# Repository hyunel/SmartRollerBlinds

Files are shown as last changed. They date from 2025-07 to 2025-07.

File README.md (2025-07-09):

<p align="right">
English | <a href="./README.zh.md">中文</a>
</p>

# SmartRollerBlinds
> A low-cost, high-precision DIY smart roller blind motor solution based on ESP32-C3.

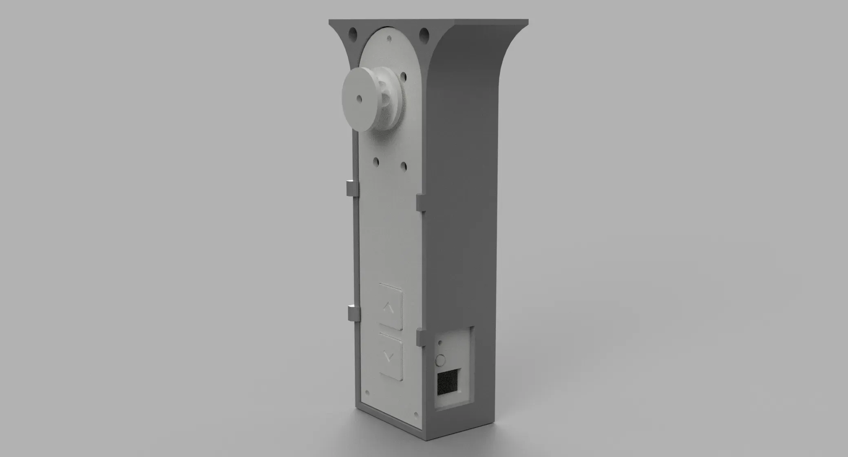
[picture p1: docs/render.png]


<p align="center">
    
    
    
</p>

## ✨ Features

*   **🛠️ Low-Cost DIY**: Core components are common materials, easy to source and assemble.
*   **🎯 Precise Positioning**: PID motor position control, supports setting a specific open/close percentage.
*   **💾 Power-off Memory**: Calibrated open/close positions and the current motor position are saved, no recalibration is needed after a power outage.
*   **🔗 Multiple Control Methods**: Supports MQTT, physical buttons, serial debugging, etc., making it flexible for different scenarios.
*   **🏠 Smart Home Integration**: Supports Home Assistant MQTT auto-discovery for seamless integration into your smart home system.

## 📦 Bill of Materials (BOM)
*   Mainboard (PCB)
*   12V Power Supply
*   370 Geared Motor (12V, 40 RPM, with encoder)  
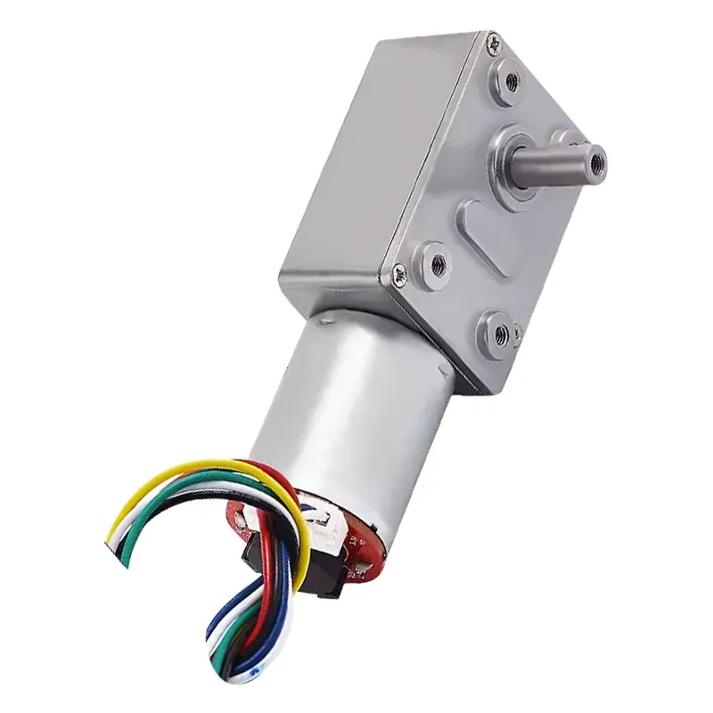
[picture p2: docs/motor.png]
Motor with encoder
    
*   3D-printed case and bracket
*   Screws

## 🚀 Getting Started

Please follow the steps below to install and configure the device.

### 1. Hardware Assembly and Installation

> **⚠️ Note on Pull Cords**
> 
> This device is **not compatible** with pull cords that have large **connectors or stoppers** (common on beaded chains). The connector can get stuck in the motor's gear, causing malfunction or damage.
> 
> Before installation, please ensure your pull cord is a **continuous closed loop**. If your cord has a connector:
> *   Replace it with a seamless, continuous closed-loop cord.
> *   Carefully remove the connector and securely join the ends using methods like tying a knot, sewing with a needle and thread, or binding with a thin string.

#### Assembly Steps

1.  **Mount the Bracket**: Use glue or screws to fix the motor bracket in a suitable position. Ensure the pull cord can be driven by the motor and remains taut.
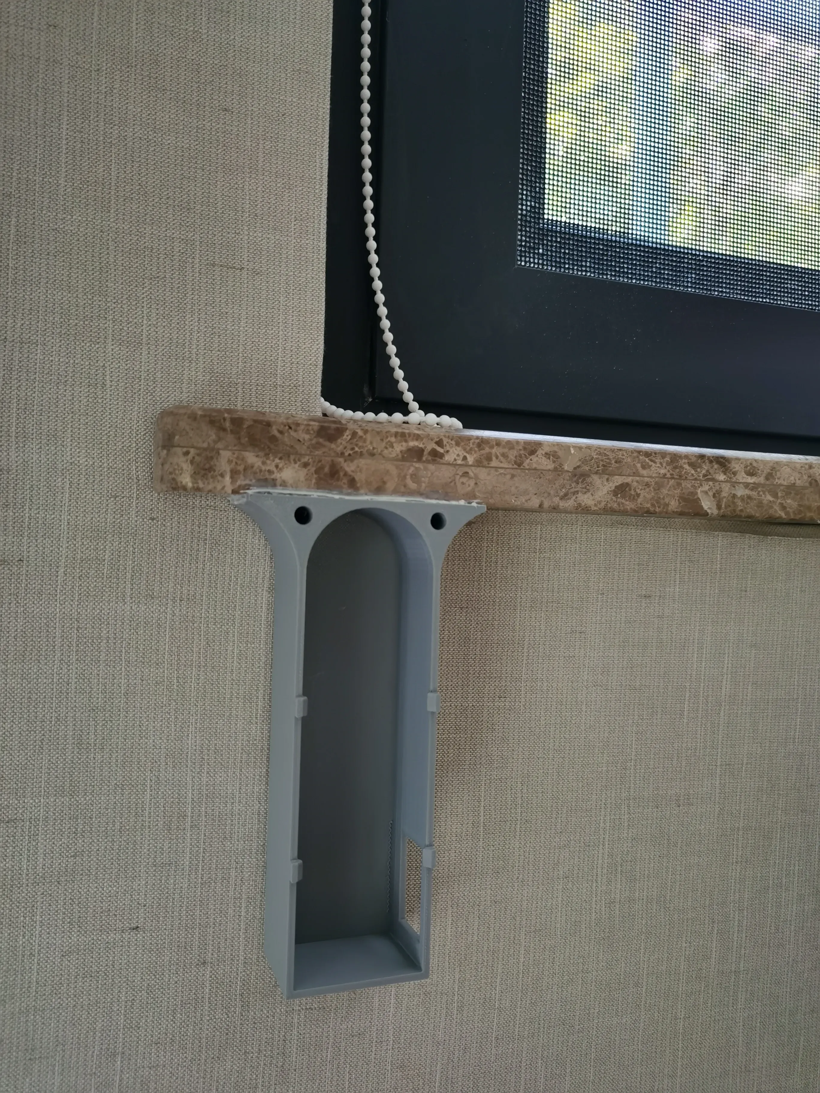
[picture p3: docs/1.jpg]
Assembly Diagram 1
    

2.  **Assemble the Motor**: Place the motor and the mainboard into the 3D-printed case and complete the wiring.
    > **💡 Hardware Tip: Regarding Circuit Soldering**
    >
    > The components `R1`, `C3`, and `R3` on the PCB are reserved for a motor current sampling feature. **The current firmware version does not use this feature**.
    > Therefore, during soldering:
    > *   `R1` and `C3` can be left **uninstalled**.
    > *   The pads for `R3` must be **shorted** (you can use a `0R` resistor or simply bridge the pads with a blob of solder).
    <p align="center">
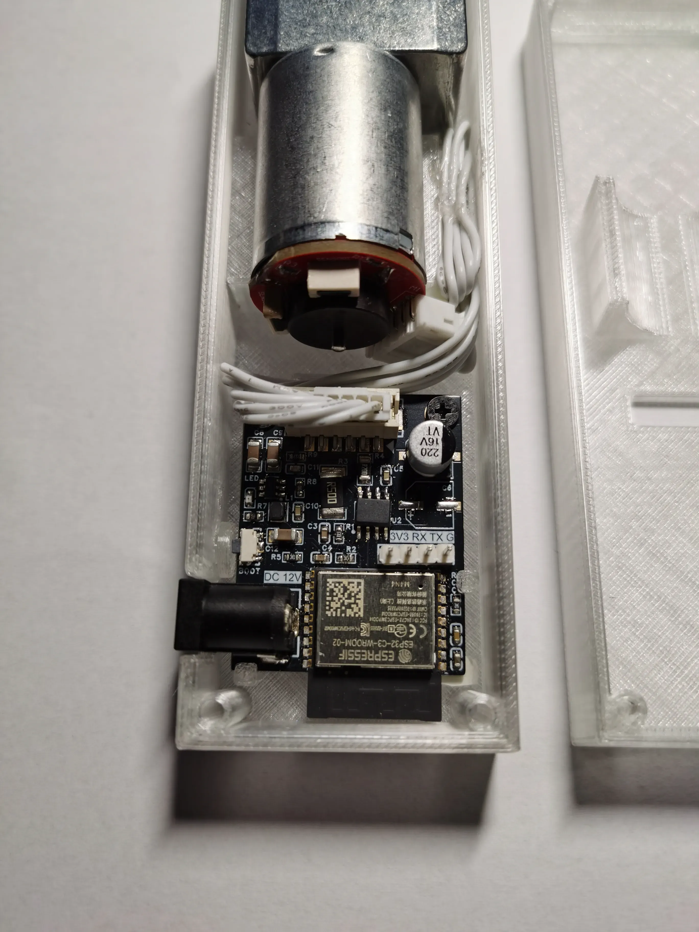
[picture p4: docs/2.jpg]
Assembly Diagram 2
      
    </p>

3.  **Install the Main Unit**: Place the assembled motor unit into the bracket.
    <p align="center">
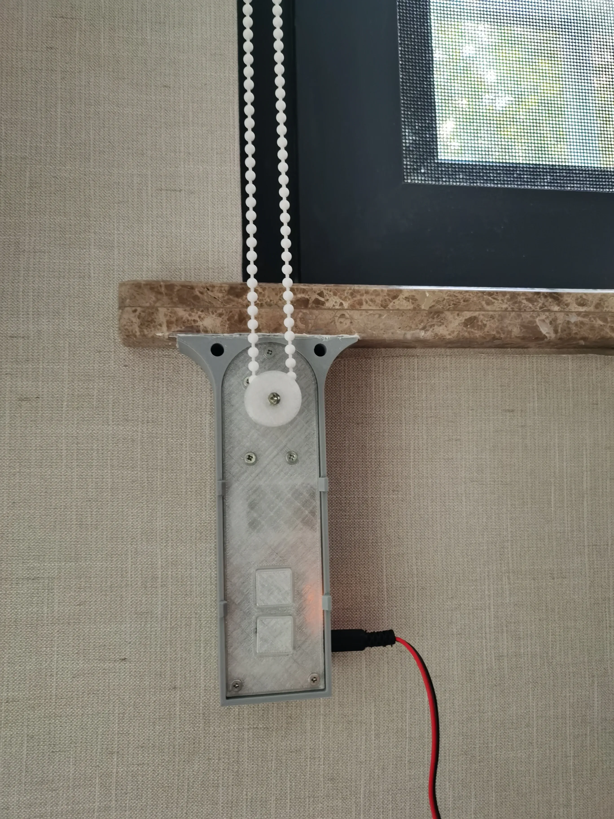
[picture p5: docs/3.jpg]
Assembly Diagram 3
      
    </p>

### 2. Firmware Compilation
Using the **VSCode + ESP-IDF extension** for development is highly recommended.

1.  **Environment Setup**: Clone this repository, open the `firmware` folder, and ensure the ESP-IDF development environment is correctly installed and configured.
2.  **Custom Configuration**:
    *   **VSCode**: Click the gear icon `⚙️` on the bottom status bar or run the `ESP-IDF: SDK Configuration editor` command to open the graphical configuration interface.
    *   **Command Line**: Run `idf.py menuconfig` in the project's root directory.
    *   Find the `SmartRollerBlinds Configuration` menu to make your desired changes (e.g., GPIO, motor direction).
3.  **Compile the Firmware**:
    *   **VSCode**: Click the `Build` button on the bottom status bar.
    *   **Command Line**: Run `idf.py build`.

### 3. Flashing the Firmware
You can flash the firmware directly using one of the following methods:

*   **VSCode**: Click the `Flash` button on the bottom status bar. The extension will handle everything automatically.
*   **Command Line**: Run `idf.py -p YOUR_SERIAL_PORT flash`.

---

### ⚠️ **Important: Disable JTAG Pins**
> To prevent the motor from turning unexpectedly during power-up or reset due to indeterminate pin states, you must perform a one-time eFuse burn to disable the JTAG feature after the initial flashing.

**Note: This operation is permanent and irreversible!**

1.  Keep the mainboard connected to your computer via serial.
2.  Open the IDF terminal and execute the following command. Remember to replace `YOUR_SERIAL_PORT` with your device's actual serial port.
    ```bash
    espefuse --port YOUR_SERIAL_PORT burn_efuse DIS_PAD_JTAG
    ```

3.  When you see `eFuse burned.` or a similar success message, the process is complete. You can now disconnect the device and proceed to the next steps.

---

### 4. Network Configuration
1.  **Connect Power**: Ensure the motor is connected to a 12V power supply. The device will automatically enter provisioning mode on first power-up or after a reset.
2.  **Enter Provisioning Mode**: The onboard LED will **blink rapidly** when the device is in provisioning mode.
3.  **Connect to Hotspot**: Use your phone or computer to connect to the Wi-Fi hotspot named `SRB-<mac_address>`.
4.  **Configure Credentials**:
    *   After connecting, a configuration page will pop up automatically.
        <p align="center">
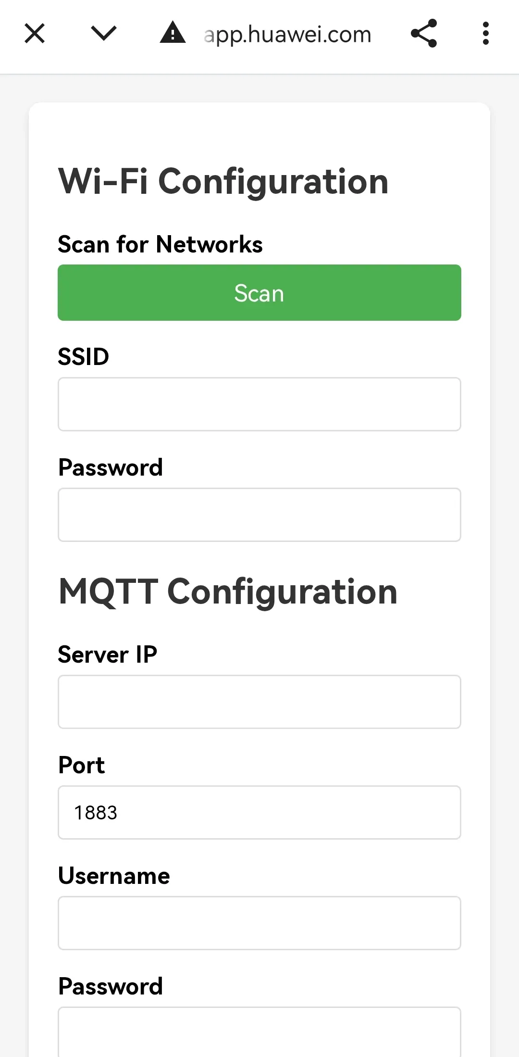
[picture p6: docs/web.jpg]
Web Configuration
          
        </p>
    *   Enter your home **Wi-Fi name (SSID)** and **password**.
    *   Enter your **MQTT server address**, **port** (default `1883`), and username/password if required.
    *   Click "Save".
5.  **Configuration Complete**: The device will restart and connect to your configured network. Once successful, the LED will become **solid on**.
    *   **Tip**: If MQTT auto-discovery is enabled in your Home Assistant, the device will now automatically appear in the device list.

### 5. Travel Calibration

On first use, you need to calibrate the fully open (upper limit) and fully closed (lower limit) positions of the blinds.

1.  **Set the Upper Limit**:
    *   **Long-press** the `UP ▲` button, and the motor will move upwards.
    *   When the blinds reach your desired **fully open** position, **short-press** the `DOWN ▼` button. The motor will stop, and the upper limit is now saved.
2.  **Set the Lower Limit**:
    *   **Long-press** the `DOWN ▼` button, and the motor will move downwards.
    *   When the blinds reach your desired **fully closed** position, **short-press** the `UP ▲` button. The motor will stop, and the lower limit is now saved.

Calibration complete! You can now control your blinds via the buttons or your smart home system.

## 🏠 Smart Home Integration

If MQTT auto-discovery is enabled in your Home Assistant, the device will automatically appear in the device list after connecting to the network, with no manual configuration required.

<p align="center">
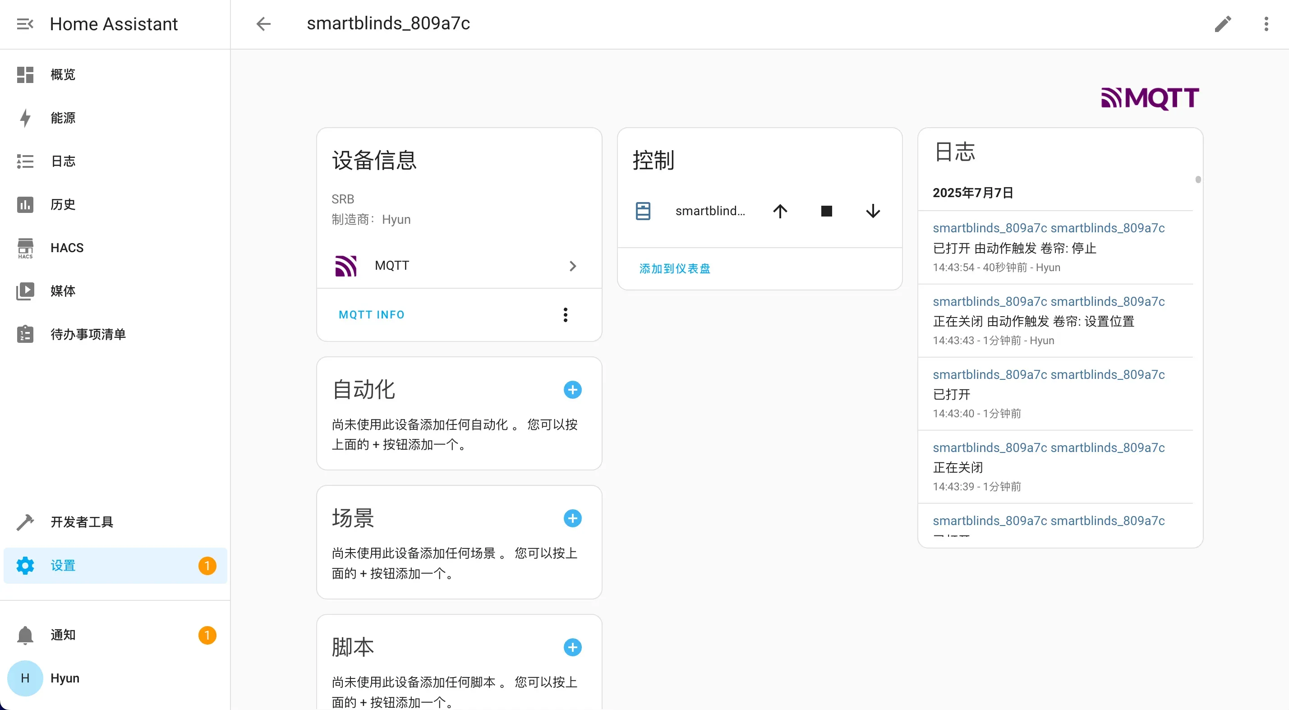
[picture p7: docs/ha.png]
Home Assistant Integration Showcase
    
</p>

## 🕹️ Usage

| Action | Function |
| :--- | :--- |
| **Short-press** `UP ▲` / `DOWN ▼` | Move to calibrated upper/lower limit; Press opposite key during movement to stop. |
| **Double-press** `UP ▲` / `DOWN ▼` | Nudge up/down a short distance. |
| **Long-press** `UP ▲` or `DOWN ▼` | Start travel calibration (**will overwrite previous settings**). |
| **Long-press** `Boot` button (side) | Enter Wi-Fi provisioning mode (**will delete saved Wi-Fi credentials**). |

## ⚙️ Advanced Configuration

If you wish to modify default behaviors (e.g., motor direction, nudge distance, GPIO pin definitions), you can do so via `menuconfig`.

*   **Command Line Method**: Run `idf.py menuconfig` in the project's root directory, then navigate to the `SmartRollerBlinds Configuration` menu to make changes.
*   **VSCode Method**: Using the ESP-IDF extension in VSCode, click the gear icon `⚙️` on the bottom status bar to open the graphical configuration interface.

## 🔧 Troubleshooting

### PID Tuning

**Symptom**: The motor jitters, is excessively noisy during operation, or fails to hold its position stably.

This usually means the default PID parameters are not suitable for your specific motor or load and require manual tuning. You can adjust the parameters in one of three ways:

1.  **Via Serial Port**
    -   Connect to the device's serial port and send a command in the following format:
        ```bash
        set_pid <kp> <ki> <kd>
        ```
    *   Example: `set_pid 1.2 0.5 0.8`

2.  **Via MQTT**
    *   Publish a payload with the same format to the `<base_topic>/command` MQTT topic.
    *   For example, in Home Assistant's `MQTT -> Publish a packet` tool:
        *   **Topic**: `blinds/living_room/command`
        *   **Payload**: `set_pid 1.2 0.5 0.8`

3.  **Via menuconfig**
    *   In the `SmartRollerBlinds Configuration` menu within `idf.py menuconfig`, find the PID-related parameters, modify them directly, then recompile and flash the firmware.

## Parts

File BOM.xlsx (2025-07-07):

No. | Quantity | Comment | Designator | Footprint | Value
1 | 1 | 10uF | C1 | C0603 | 10uF
2 | 3 | 100nF | C2,C5,C10 | C0603 | 100nF
3 | 2 | 1uF | C3,C4 | C0603 | 1uF
4 | 2 | 220uF | C6,C7 | CAP-SMD_BD6.3-L6.6-W6.6-FD | 220uF
5 | 3 | 22uF | C8,C9,C12 | C1206 | 22uF
6 | 1 | 100pF | C11 | C0603 | 100pF
7 | 1 | DC-005_2.0 | DC1 | DC-2.0
8 | 1 | HDR-F_2.54_1x4P | H1 | HDR-TH_4P-P2.54-V-F
9 | 1 | 3.3uH | L1 | IND-SMD_L2.5-W2.0_SWPA252012S | 3.3uH
10 | 1 | LED_0603-R | LED1 | LED_0603
11 | 1 | 220R | R1 | R0603 | 220R
12 | 4 | 10K | R2,R5,R6,R7 | R0603 | 10K
13 | 1 | 0.5R | R3 | R2512 | 0.5R
14 | 1 | 0.2R | R4 | R1206 | 0.2R
15 | 1 | 100K | R8 | R0603 | 100K
16 | 1 | 22K | R9 | R0603 | 22K
17 | 1 | GT-TC020A-H035-L05 | SW1 | SW-SMD_GT-TC020B-H035-L05
18 | 2 | GT-TZ084B-H015-L1 | SW2,SW3 | SW-SMD_4P-L5.2-W5.2-P3.70-LS6.4
19 | 1 | ESP32-C3-WROOM | U1 | BULETM-SMD_ESPRESSIF_ESP32-C3-WROOM-02-N4-4MB
20 | 1 | DRV8870DDAR | U2 | HSOP-8_L5.0-W4.0-P1.27-LS6.2-BL-EP
21 | 1 | BX-PH2.0-6PLT | U3 | CONN-SMD_6P-P2.00_BX-PH2.0-6PLT
22 | 1 | ME3121AM6G | U4 | SOT-23-6_L2.9-W1.6-P0.95-LS2.8-BR
23 | 1 | 370微型直流减速电机 调速涡轮蜗杆低速小马达12v24v编码器带测速
24 | 1 | PH2.0 同向6P双头线
25 | 5 | 螺丝 M3*5*5
26 | 3 | 螺丝 M2.5*22
27 | 2 | 螺丝 M2.6*4 (自攻)

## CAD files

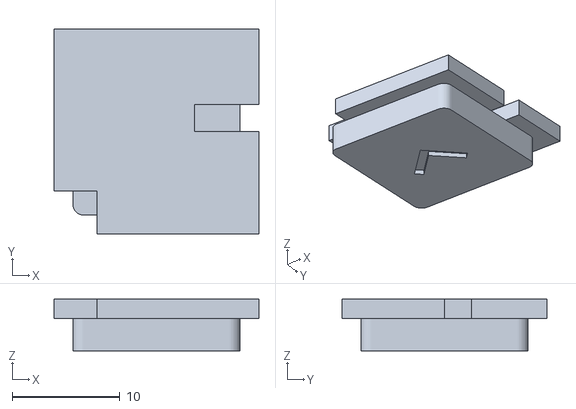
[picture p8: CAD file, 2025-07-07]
3d/Button Down.stl
19.0 x 19.0 x 4.80

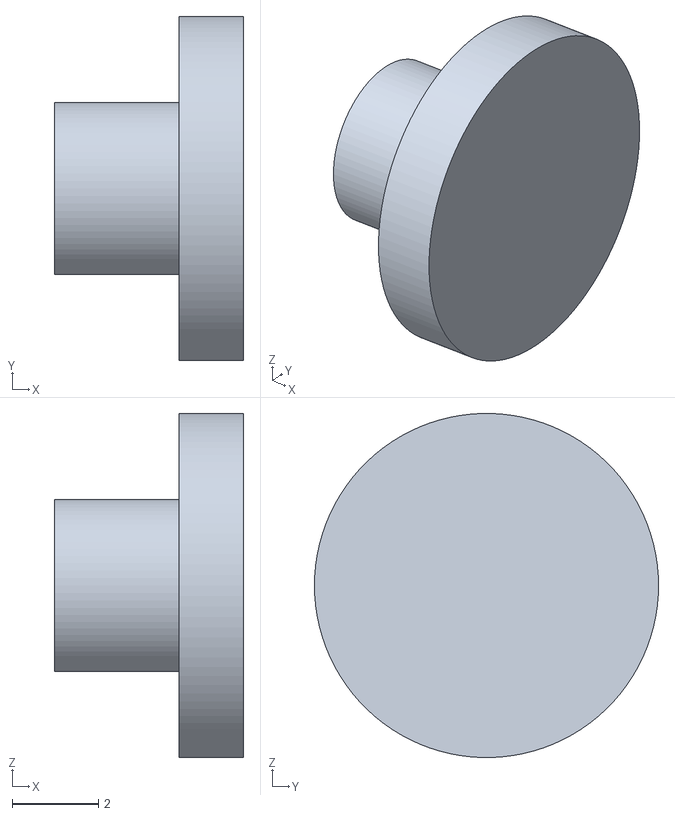
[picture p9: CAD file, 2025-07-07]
3d/Button - Boot.stl
4.40 x 8.00 x 8.00

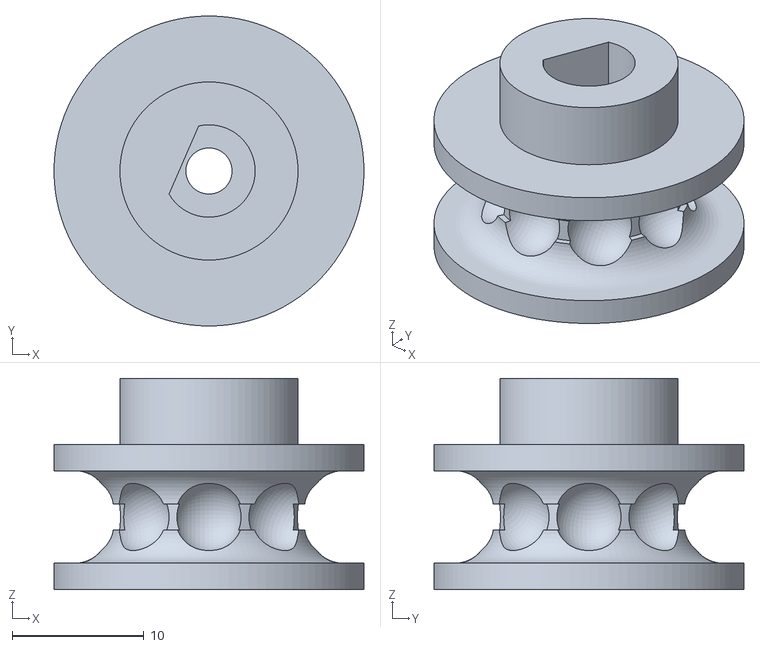
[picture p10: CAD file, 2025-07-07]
3d/Wheel.stl
23.5 x 23.5 x 16.0

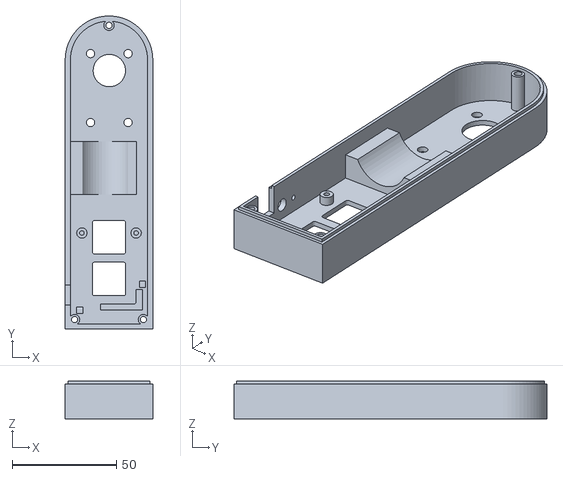
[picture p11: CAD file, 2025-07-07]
3d/Body - Front.stl
42.0 x 150.0 x 18.0

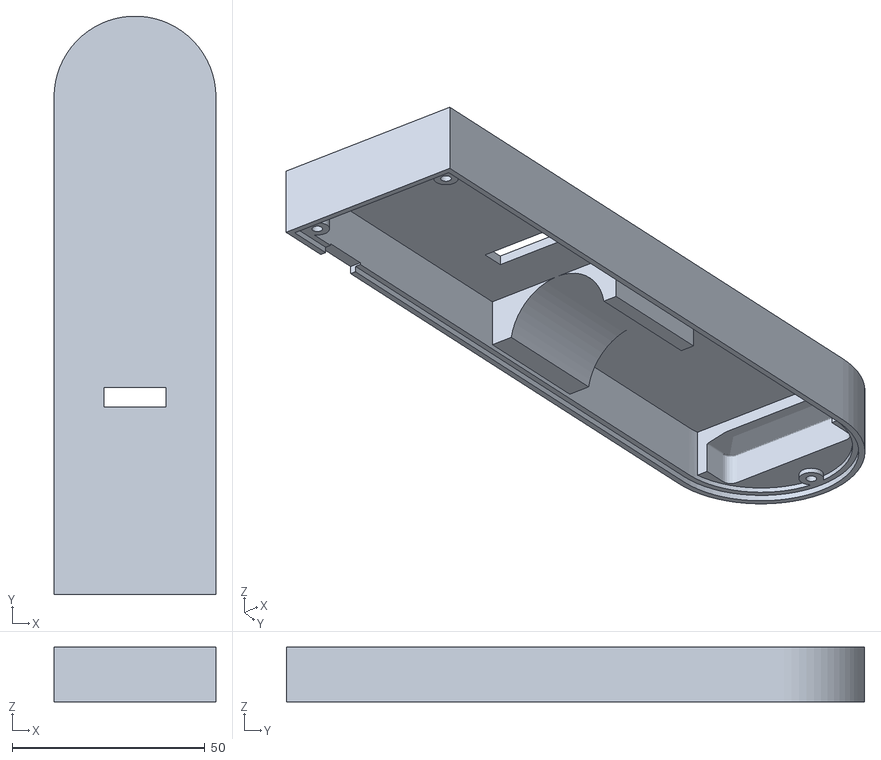
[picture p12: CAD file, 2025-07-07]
3d/Body - Back.stl
42.0 x 150.0 x 14.2

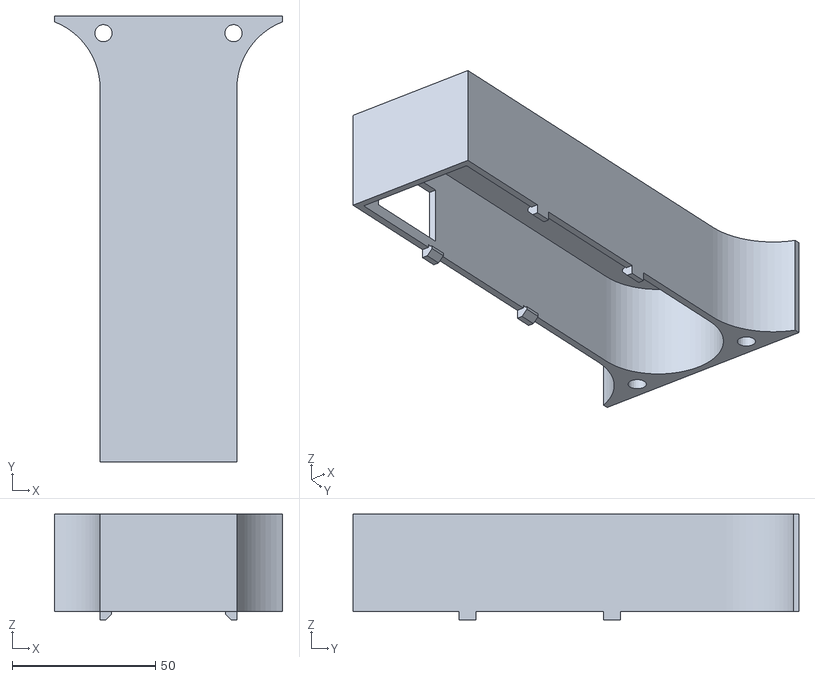
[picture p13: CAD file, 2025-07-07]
3d/Holder.stl
79.8 x 155.8 x 37.0

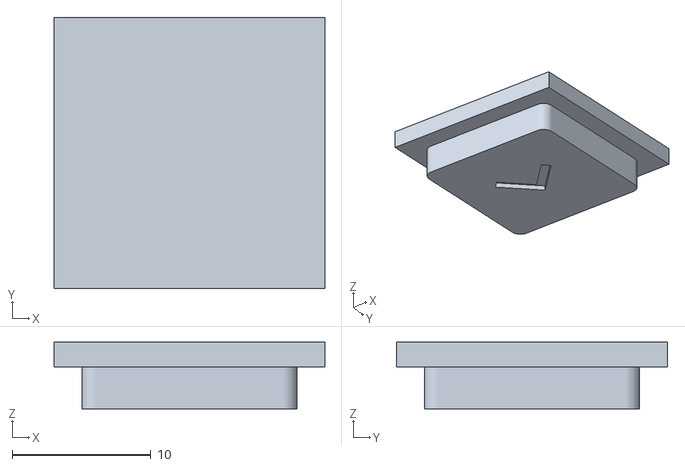
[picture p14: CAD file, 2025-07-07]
3d/Button Up.stl
19.5 x 19.5 x 4.80

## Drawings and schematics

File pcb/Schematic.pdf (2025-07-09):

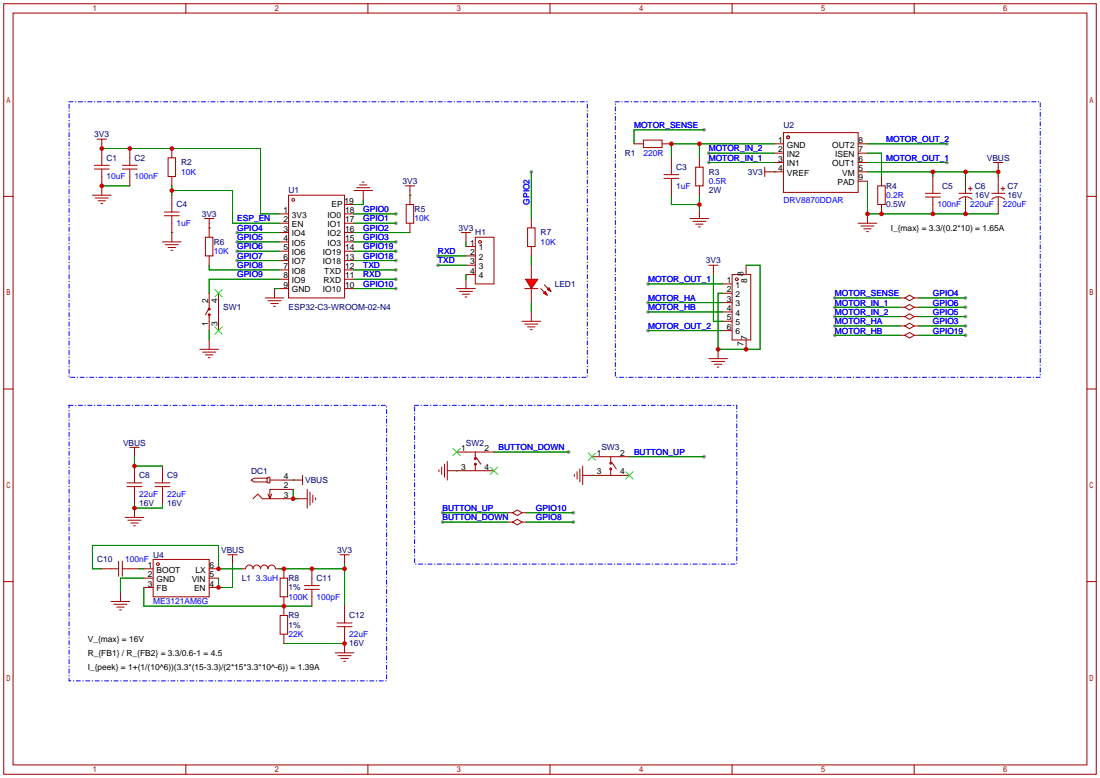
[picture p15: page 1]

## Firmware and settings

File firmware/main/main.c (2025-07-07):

#include <stdio.h>
#include <string.h>
#include <stdlib.h>
#include "freertos/FreeRTOS.h"
#include "freertos/task.h"
#include "esp_system.h"
#include "esp_log.h"
#include "driver/uart.h"
#include "nvs_flash.h"
#include "modules/motor.h"
#include "modules/button.h"
#include "modules/led_control.h"
#include "modules/wifi_manager.h"
#include "modules/dns_server.h"
#include "modules/command_handler.h" // Add command handler
#include "sdkconfig.h"
#include "esp_wifi.h"

#define TAG "MAIN"
#define UART_NUM UART_NUM_0
#define UART_BUF_SIZE (1024)
#define TASK_STACK_SIZE 2048

static motor_handle_t main_motor_handle;

static void process_command(char *cmd_line) {
    if (cmd_line == NULL || strlen(cmd_line) == 0) {
        return;
    }
    
    // Pass all commands directly to the central handler.
    char response_buffer[512]; // Increased buffer size for help text
    cmd_handle_command_string(cmd_line, main_motor_handle, response_buffer, sizeof(response_buffer));
    
    if (strlen(response_buffer) > 0) {
        printf("%s\n", response_buffer);
    }
}

// --- UART Task ---

static void uart_task(void *arg)
{
    uart_config_t uart_config = {
        .baud_rate = 115200,
        .data_bits = UART_DATA_8_BITS,
        .parity    = UART_PARITY_DISABLE,
        .stop_bits = UART_STOP_BITS_1,
        .flow_ctrl = UART_HW_FLOWCTRL_DISABLE,
        .source_clk = UART_SCLK_DEFAULT,
    };
    uart_driver_install(UART_NUM, UART_BUF_SIZE * 2, 0, 0, NULL, 0);
    uart_param_config(UART_NUM, &uart_config);
    uart_set_pin(UART_NUM, UART_PIN_NO_CHANGE, UART_PIN_NO_CHANGE, UART_PIN_NO_CHANGE, UART_PIN_NO_CHANGE);

    uint8_t* data = (uint8_t*) malloc(UART_BUF_SIZE);
    char line_buffer[256];
    int line_pos = 0;

    printf("\n--- Serial Console Initialized ---\n");
    printf("Type 'help' for a list of commands.\n");
    printf("esp32> ");
    fflush(stdout);


    while (1) {
        int len = uart_read_bytes(UART_NUM, data, UART_BUF_SIZE, 20 / portTICK_PERIOD_MS);
        if (len > 0) {
            for (int i = 0; i < len; i++) {
                char c = data[i];
                if (c == '\r' || c == '\n') {
                    // Echo the newline
                    uart_write_bytes(UART_NUM, "\r\n", 2);

                    line_buffer[line_pos] = '\0'; // Null-terminate the string
                    if (line_pos > 0) {
                        process_command(line_buffer);
                    }
                    line_pos = 0; // Reset for next command
                    printf("esp32> ");
                    fflush(stdout);
                } else if (c == '\b' || c == 127) { // Handle backspace
                    if (line_pos > 0) {
                        line_pos--;
                        // Erase character on the terminal
                        uart_write_bytes(UART_NUM, "\b \b", 3);
                    }
                } else if (line_pos < (sizeof(line_buffer) - 1)) {
                    // Echo character
                    uart_write_bytes(UART_NUM, (const char*)&c, 1);
                    line_buffer[line_pos++] = c;
                }
            }
        }
    }
    free(data);
}


void app_main(void)
{
    // Initialize NVS
    esp_err_t ret = nvs_flash_init();
    if (ret == ESP_ERR_NVS_NO_FREE_PAGES || ret == ESP_ERR_NVS_NEW_VERSION_FOUND) {
      ESP_ERROR_CHECK(nvs_flash_erase());
      ret = nvs_flash_init();
    }
    ESP_ERROR_CHECK(ret);

    // Initialize the event loop
    ESP_ERROR_CHECK(esp_event_loop_create_default());

    // Initialize Motor
    ESP_ERROR_CHECK(motor_init(&main_motor_handle));

    // Initialize Buttons
    button_module_init(main_motor_handle);

    // Initialize LED
    led_control_init();

    // Start the console task
    xTaskCreate(uart_task, "uart_task", TASK_STACK_SIZE * 2, NULL, 10, NULL);

    // Initialize WiFi Manager
    ESP_ERROR_CHECK(wifi_manager_init(main_motor_handle));

    // Start DNS server if in AP mode
    wifi_mode_t mode;
    esp_wifi_get_mode(&mode);
    if (mode == WIFI_MODE_AP || mode == WIFI_MODE_APSTA) {
        dns_server_config_t config = DNS_SERVER_CONFIG_SINGLE("*" /* all A queries */, "WIFI_AP_DEF" /* softAP netif ID */);
        start_dns_server(&config);
    }
}

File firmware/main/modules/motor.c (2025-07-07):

#include "motor.h"
#include "sdkconfig.h"
#include "esp_log.h"
#include "freertos/FreeRTOS.h"
#include "freertos/task.h"
#include "freertos/queue.h"
#include "freertos/semphr.h"
#include "driver/ledc.h"
#include "driver/gpio.h"
#include "pid_ctrl.h"
#include "nvs_flash.h"
#include "nvs.h"
#include "esp_event.h"
#include <math.h>
#include <string.h>

#define TAG "MOTOR"

ESP_EVENT_DEFINE_BASE(MOTOR_EVENTS);

// --- Configuration Constants ---
#define LEDC_TIMER              LEDC_TIMER_0
#define LEDC_MODE               LEDC_LOW_SPEED_MODE
#define LEDC_CHANNEL_A          LEDC_CHANNEL_0
#define LEDC_CHANNEL_B          LEDC_CHANNEL_1
#define LEDC_DUTY_RES           LEDC_TIMER_10_BIT
#define LEDC_FREQUENCY          (20000)

#define PID_MAX_OUTPUT          100.0f
#define PID_MIN_OUTPUT         -100.0f
#define PID_CONTROL_PERIOD_MS   10

#define NVS_NAMESPACE           "motor"
#define NVS_POSITION_KEY        "position"
#define NVS_FULLY_CLOSED_KEY    "fully_closed"
#define NVS_SPEED_KEY           "def_speed"

#define MOTOR_CMD_QUEUE_LEN     10

// --- Type Definitions ---

typedef enum {
    CMD_SET_TARGET,
    CMD_MOVE_RELATIVE,
    CMD_STOP,
    CMD_START_CALIBRATION_UP,
    CMD_START_CALIBRATION_DOWN,
} motor_command_type_t;

typedef struct {
    motor_command_type_t type;
    int32_t position;
    float max_speed_pps;
} motor_command_t;

// The main struct holding the state of a motor instance
struct motor_control_t {
    pid_ctrl_block_handle_t pid_controller;
    pid_ctrl_parameter_t pid_params;
    QueueHandle_t cmd_queue;
    nvs_handle_t nvs_handle;
    SemaphoreHandle_t lock;

    // Volatile state updated by ISR or multiple tasks
    volatile int32_t current_position;
    volatile int8_t last_hall_state;

    // State controlled by the PID task
    int32_t target_position;
    int32_t fully_closed_position;
    float default_speed_pps;
    motor_state_t current_state;
    motor_direction_t current_direction;
    bool is_calibrated;
};

// --- Forward Declarations ---
static void motor_pid_control_task(void *pvParameters);
static esp_err_t motor_set_pwm_duty(float duty_percent);
static void IRAM_ATTR hall_encoder_isr_handler(void* arg);
static void process_command(motor_handle_t handle, const motor_command_t *cmd);
static void motor_set_state(motor_handle_t handle, motor_state_t new_state);
static void motor_initiate_movement(motor_handle_t handle, int32_t target, float speed, motor_state_t state);

// --- Public API Implementation ---

esp_err_t motor_init(motor_handle_t *motor_handle) {
    ESP_LOGI(TAG, "Initializing new motor instance...");

    // Allocate memory for the motor control struct
    motor_handle_t handle = (motor_handle_t)calloc(1, sizeof(struct motor_control_t));
    if (!handle) {
        ESP_LOGE(TAG, "Failed to allocate memory for motor handle");
        return ESP_ERR_NO_MEM;
    }

    // Hardware Init: LEDC PWM (assuming single motor for now, could be parameterized)
    ledc_timer_config_t ledc_timer = { .speed_mode = LEDC_MODE, .timer_num = LEDC_TIMER, .duty_resolution = LEDC_DUTY_RES, .freq_hz = LEDC_FREQUENCY, .clk_cfg = LEDC_AUTO_CLK };
    ESP_ERROR_CHECK(ledc_timer_config(&ledc_timer));
    ledc_channel_config_t ledc_channel_a = { .speed_mode = LEDC_MODE, .channel = LEDC_CHANNEL_A, .timer_sel = LEDC_TIMER, .intr_type = LEDC_INTR_DISABLE, .gpio_num = CONFIG_PIN_MOTOR_A, .duty = 0, .hpoint = 0 };
    ESP_ERROR_CHECK(ledc_channel_config(&ledc_channel_a));
    ledc_channel_config_t ledc_channel_b = { .speed_mode = LEDC_MODE, .channel = LEDC_CHANNEL_B, .timer_sel = LEDC_TIMER, .intr_type = LEDC_INTR_DISABLE, .gpio_num = CONFIG_PIN_MOTOR_B, .duty = 0, .hpoint = 0 };
    ESP_ERROR_CHECK(ledc_channel_config(&ledc_channel_b));

    // Hardware Init: Hall Sensor GPIO Interrupts
    gpio_config_t io_conf = { .pin_bit_mask = (1ULL << CONFIG_PIN_MOTOR_HA) | (1ULL << CONFIG_PIN_MOTOR_HB), .mode = GPIO_MODE_INPUT, .pull_up_en = GPIO_PULLUP_ENABLE, .intr_type = GPIO_INTR_ANYEDGE };
    ESP_ERROR_CHECK(gpio_config(&io_conf));
    ESP_ERROR_CHECK(gpio_install_isr_service(0));
    // Pass the handle to the ISR
    ESP_ERROR_CHECK(gpio_isr_handler_add(CONFIG_PIN_MOTOR_HA, hall_encoder_isr_handler, handle));
    ESP_ERROR_CHECK(gpio_isr_handler_add(CONFIG_PIN_MOTOR_HB, hall_encoder_isr_handler, handle));

    // Software Init: PID Controller
    handle->pid_params = (pid_ctrl_parameter_t) {
        .kp = atof(CONFIG_MOTOR_PID_KP),
        .ki = atof(CONFIG_MOTOR_PID_KI),
        .kd = atof(CONFIG_MOTOR_PID_KD),
        .min_output = PID_MIN_OUTPUT,
        .max_output = PID_MAX_OUTPUT,
        .cal_type = PID_CAL_TYPE_INCREMENTAL,
    };
    pid_ctrl_config_t pid_config = { .init_param = handle->pid_params };
    ESP_ERROR_CHECK(pid_new_control_block(&pid_config, &handle->pid_controller));

    // Software Init: Command Queue
    handle->cmd_queue = xQueueCreate(MOTOR_CMD_QUEUE_LEN, sizeof(motor_command_t));
    if (!handle->cmd_queue) {
        ESP_LOGE(TAG, "Failed to create command queue");
        free(handle);
        return ESP_ERR_NO_MEM;
    }

    // Software Init: Mutex for thread safety
    handle->lock = xSemaphoreCreateMutex();
    if (!handle->lock) {
        ESP_LOGE(TAG, "Failed to create mutex");
        vQueueDelete(handle->cmd_queue);
        free(handle);
        return ESP_ERR_NO_MEM;
    }

    // State Init: Load from NVS
    nvs_handle_t nvs_handle;
    esp_err_t err = nvs_open(NVS_NAMESPACE, NVS_READONLY, &nvs_handle);
    if (err == ESP_OK) {
        if (nvs_get_i32(nvs_handle, NVS_POSITION_KEY, (int32_t*)&handle->current_position) == ESP_OK) {
            ESP_LOGI(TAG, "Loaded position %" PRId32 " from NVS.", handle->current_position);
            handle->target_position = handle->current_position;
            handle->is_calibrated = true;
        } else {
            ESP_LOGW(TAG, "Could not load position from NVS. Motor needs calibration.");
            handle->is_calibrated = false;
        }

        if (nvs_get_i32(nvs_handle, NVS_FULLY_CLOSED_KEY, &handle->fully_closed_position) == ESP_OK) {
            ESP_LOGI(TAG, "Loaded fully closed position %" PRId32 " from NVS.", handle->fully_closed_position);
        } else {
            handle->fully_closed_position = 0;
            ESP_LOGW(TAG, "Fully closed position not set. Percentage moves will not work.");
        }
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

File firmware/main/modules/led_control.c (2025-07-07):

#include "led_control.h"
#include "freertos/FreeRTOS.h"
#include "freertos/task.h"
#include "freertos/semphr.h"
#include "driver/ledc.h"
#include "esp_log.h"
#include "sdkconfig.h"
#include <math.h>
#include "esp_event.h"
#include "esp_wifi.h"
#include "motor.h"

#define TAG "LED_CONTROL"

// LEDC configuration for the status LED
#define LEDC_TIMER              LEDC_TIMER_1
#define LEDC_MODE               LEDC_LOW_SPEED_MODE
#define LEDC_CHANNEL            LEDC_CHANNEL_2
#define LEDC_DUTY_RES           LEDC_TIMER_13_BIT // 13-bit resolution (0-8191) for smooth breathing
#define LEDC_FREQUENCY          (5000) // 5 kHz frequency

#define BREATHING_PERIOD_MS     3000 // Total time for one breath (in and out)
#define BREATHING_STEPS         100  // Number of steps for the animation

static led_state_t g_current_led_state = LED_STATE_OFF;
static SemaphoreHandle_t g_state_mutex;
static TaskHandle_t g_led_task_handle = NULL;

static void status_event_handler(void* arg, esp_event_base_t event_base,
                                 int32_t event_id, void* event_data)
{
    if (event_base == WIFI_EVENT) {
        if (event_id == WIFI_EVENT_STA_START || event_id == WIFI_EVENT_STA_DISCONNECTED) {
            // Wi-Fi Connecting State
            led_control_set_state(LED_STATE_BREATHING);
        } else if (event_id == WIFI_EVENT_AP_START) {
            // Wi-Fi Provisioning (AP Mode)
            led_control_set_state(LED_STATE_BLINK_FAST);
        }
    } else if (event_base == IP_EVENT) {
        if (event_id == IP_EVENT_STA_GOT_IP) {
            // Wi-Fi Connected and Idle
            led_control_set_state(LED_STATE_ON);
        }
    } else if (event_base == MOTOR_EVENTS) {
        if (event_id == MOTOR_EVENT_STATE_CHANGED) {
            motor_state_t new_state = *(motor_state_t*)event_data;
            switch (new_state) {
                case MOTOR_STATE_MOVING:
                case MOTOR_STATE_CALIBRATING:
                    // Motor is running
                    led_control_set_state(LED_STATE_BLINK_SLOW);
                    break;
                case MOTOR_STATE_IDLE:
                    // Motor is idle, revert to Wi-Fi status
                    {
                        wifi_ap_record_t ap_info;
                        if (esp_wifi_sta_get_ap_info(&ap_info) == ESP_OK) {
                            // Connected and Idle
                            led_control_set_state(LED_STATE_ON);
                        } else {
                            // Disconnected and Idle
                            led_control_set_state(LED_STATE_BREATHING);
                        }
                    }
                    break;
                case MOTOR_STATE_ERROR:
                    // Motor Error
                    led_control_set_state(LED_STATE_BLINK_FAST);
                    break;
            }
        }
    }
}

static void led_control_task(void *pvParameters);

void led_control_init(void) {
    // 1. Configure LEDC Timer
    ledc_timer_config_t ledc_timer = {
        .speed_mode       = LEDC_MODE,
        .timer_num        = LEDC_TIMER,
        .duty_resolution  = LEDC_DUTY_RES,
        .freq_hz          = LEDC_FREQUENCY,
        .clk_cfg          = LEDC_AUTO_CLK
    };
    ESP_ERROR_CHECK(ledc_timer_config(&ledc_timer));

    // 2. Configure LEDC Channel
    ledc_channel_config_t ledc_channel = {
        .speed_mode     = LEDC_MODE,
        .channel        = LEDC_CHANNEL,
        .timer_sel      = LEDC_TIMER,
        .intr_type      = LEDC_INTR_DISABLE,
        .gpio_num       = CONFIG_PIN_LED,
        .duty           = 0,
        .hpoint         = 0
    };
    ESP_ERROR_CHECK(ledc_channel_config(&ledc_channel));

    // 3. Create Mutex and Task
    g_state_mutex = xSemaphoreCreateMutex();
    if (g_state_mutex == NULL) {
        ESP_LOGE(TAG, "Failed to create state mutex");
        return;
    }

    xTaskCreate(led_control_task, "led_control_task", 2048, NULL, 5, &g_led_task_handle);
    ESP_LOGI(TAG, "LED control task started");

    // Register the event handler to listen for system-wide status changes
    ESP_ERROR_CHECK(esp_event_handler_register(WIFI_EVENT, ESP_EVENT_ANY_ID, &status_event_handler, NULL));
    ESP_ERROR_CHECK(esp_event_handler_register(IP_EVENT, IP_EVENT_STA_GOT_IP, &status_event_handler, NULL));
    ESP_ERROR_CHECK(esp_event_handler_register(MOTOR_EVENTS, ESP_EVENT_ANY_ID, &status_event_handler, NULL));
}

void led_control_set_state(led_state_t new_state) {
    if (xSemaphoreTake(g_state_mutex, portMAX_DELAY) == pdTRUE) {
        if (g_current_led_state != new_state) {
            g_current_led_state = new_state;
            // Notify the task that the state has changed
            if (g_led_task_handle != NULL) {
                xTaskNotifyGive(g_led_task_handle);
            }
        }
        xSemaphoreGive(g_state_mutex);
    }
}

static void set_led_duty(uint32_t duty) {
    ESP_ERROR_CHECK(ledc_set_duty(LEDC_MODE, LEDC_CHANNEL, duty));
    ESP_ERROR_CHECK(ledc_update_duty(LEDC_MODE, LEDC_CHANNEL));
}
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

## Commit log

2025-07-07 chore: reorganize directory structure
    [BOM.xlsx, Body - Back.stl, Body - Front.stl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]
2025-07-09 feat: device availability support
